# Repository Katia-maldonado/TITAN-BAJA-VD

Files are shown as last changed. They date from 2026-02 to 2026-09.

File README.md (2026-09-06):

## Baja SAE – Titan Racing Baja (2025-2026)
Titan Racing Baja SAE is a mechanical engineering club for students to design, build and race a custom off-road vehicle for the annual collegiate competition. Designing and building a car requires us to apply engineering problems to the real world. We gain invaluable skills in design, manufacturing, and project management that prepare us for professional careers. At **CSUF**, our Baja SAE team consists of 14 members, and our goal is to compete in the BAJA SAE Competion that is in Washougal, Washington in May 2026. We are divided into four subteams:

- Chassis / Ergonomics 
- Drivetrain  
- Suspension  
- Vehicle Dynamics / Data Acquisition  

---

## Vehicle Dynamics & Data Acquisition
For the **Vehicle Dynamics / Data Acquisition (VD/DAQ)** subteam, this focuses heavily on the electrical, sensor data, and data analysis work on the car.

We currently run **8 sensors** on the Baja car, all connected to an Arduino based DAQ system to record performance data during testing and competition runs. The system logs:

- Vehicle speed  
- Distance traveled  
- Time  
- Engine RPM  
- Secondary (CVT) RPM  
- Gyroscope data (roll, pitch, yaw)  
- 3-axis acceleration  
- Brake pressure bias  

All sensor data is routed through a **Teensy**, allowing each run to be logged directly to an microSD card. The recorded data is then processed and analyzed in **MATLAB** to evaluate vehicle performance, CVT behavior, braking balance, and driver inputs.

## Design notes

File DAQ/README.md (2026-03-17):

## System Overview

The DAQ system is responsible for collecting sensor data during testing and competition runs, logging it to an SD card. The on vehicle DAQ system is built around an **Arduino** paired with an **SD card reader shield**. Sensor inputs are recorded during each run and saved to an SD card for later analysis. This data is used to evaluate vehicle performance, driver behavior, and drivetrain response under real off road conditions.

Power for the DAQ system is supplied by the vehicle’s **12V battery**. A **buck converter** is used to step the voltage down from **12V to 5V** for sensors and components that require regulated 5V power, ensuring stable operation and protecting sensitive electronics.

---

## Sensors & Components

### Core DAQ Hardware
- Arduino  
- SD card reader shield  
- Buck converter (12V → 5V)

### Sensors / Inputs
- Brake Pressure Sensor (BPS)  
- Hall effect sensor – Secondary RPM  
- Spark plug RPM pickup – Primary RPM  
- IMU (gyroscope + accelerometer)  
- IR sensor (temperature monitoring)  
- GPS module (position / speed tracking)  
- Real Time Clock (RTC)  
- Push button (test control / marker)  
- LED indicators (system status)

---

## Data Logging & Output

During a run, sensor signals are routed into the Arduino, time stamped using the RTC, and logged to the SD card. Data is then transferred for processing and analysis in **MATLAB**, where it can be used to evaluate:

- Vehicle speed and distance trends  
- Engine and CVT RPM behavior  
- Brake pressure bias and braking consistency  
- Vehicle dynamics (roll, pitch, yaw, and acceleration)  
- Thermal behavior from IR sensor readings  
- GPS-based track mapping and run comparison  

---

## Live Transmission

In addition to SD logging, the DAQ system supports **live transmission** to allow real time monitoring during testing without removing the SD card.

### On-Vehicle Hardware (Transmitter)
- **XBee Pro 900HP – DMST**
- XBee Xplorer shield
- Antenna

### Base Station Hardware (Receiver)
- **XBee Pro 900HP – DMUT**
- Antenna

Live telemetry is primarily used during testing sessions to monitor system health and vehicle behavior in real time.

---

## To Do List

### Code  
- [x] SD card reader shield (data logging)  
- [x] Real-Time Clock (RTC) integration  
- [x] Brake Pressure Sensor (BPS)  
- [x] Hall effect sensor – Secondary RPM  
- [x] Spark plug RPM pickup – Primary RPM  
- [x] IMU (gyroscope + accelerometer)  
- [x] IR sensor (temperature monitoring)  
- [x] GPS module  
- [x] Push button (test control / marker)  
- [x] LED indicators (system status)  

### Live Transmission (Telemetry)
- [ ] XBee Pro 900HP – DMST (on-vehicle transmitter)  
- [ ] XBee Xplorer shield  
- [ ] Antenna (vehicle side)  
- [ ] XBee Pro 900HP – DMUT (base station receiver)  
- [ ] Antenna (base station)

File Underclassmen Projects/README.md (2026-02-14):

## Coding

I have a few underclassmen projects for anyone interested in writing code for **CVT tuning** and the **main DAQ harness** that will be installed on the car. These projects are a great opportunity to gain hands on experience with Arduino based data acquisition and sensor integration.

For coding related work, please reference **version 8 (v8)** of the code located in the **DAQ** or **version 9 (v9)** in the **CVT** folders. This version should be used as the baseline for development.

If you’re interested, **reach out to Katia on Discord**, and she can answer any questions you may have and help you get started.

---

### CVT DYNO

- [x] Add code to output **live data** onto a screen  
- [x] Display outputs for:
  - [x] Hall effect sensor (Primary RPM)  
  - [x] Hall effect sensor (Secondary RPM)  
  - [x] Hall effect sensor (Disk Brake RPM)  

---

### DAQ (On Vehicle)

- [ ] Code the **IMU (MPU-6050)** to record and send its data to the Arduino  
- [ ] Log IMU data onto an SD card using the **SD Card Reader Shield** (so it can be exported to Excel / MATLAB later)  
- [ ] IMU signals to record:
  - [ ] Angular velocity (gyro): **X, Y, Z**
  - [ ] Linear acceleration (accelerometer): **X, Y, Z**

> Note: The MPU-6050 is a 3-axis accelerometer and gyroscope. There are many examples available on GitHub and YouTube that can be used as references.

---

### Driver Dash Display

We are also exploring the addition of a **driver dash display** to provide live feedback during vehicle operation. The goal is to give the driver real time readings without relying on post run data analysis.

Planned display outputs include:
- Vehicle speed  
- Secondary RPM  
- CVT belt temperature (IR sensor)  

Due to the off road environment, the display must be **IP67-rated** to withstand dust, water, mud, and vibration. Many off the shelf IP67 displays are expensive, so part of this project is to find **cost effective display solutions** that can meet durability requirements.

This project may include:
- Researching low cost display options compatible with Arduino  
- Designing or selecting a **waterproof enclosure** for the screen  
- Integrating the display with the existing DAQ system  
- Ensuring readability in outdoor and high vibration conditions  

------

## CAD Fixes & Required Updates

The following items outline **specific fixes and updates** that need to be made to the existing CAD drawings for both the **CVT** and **DAQ** electrical harnesses. These updates are necessary to keep the CAD aligned with the actual electrical design and wiring standards.

---

#### CVT Harness CAD (DWG) Fixes

- Fix the electrical connections between the **battery, fuse, buck converter, and GND bus bar**
- Standardize **connector naming**:
  - All identical connectors (ex: all **JST-VH** connectors) should share the same label  
    - Example: all JST-VH connectors labeled as **C3**
- Add a **Quantity** column to the connector table
  - This applies to all repeating connectors
- Rename **BPS** to:
  - **Hall Effect – Brake Wheel RPM**

---

#### DAQ Harness CAD (DWG) Fixes

- Standardize **connector labeling**, following the same rules as the CVT harness
- Add a **Quantity** column to the connector table
- Fix electrical connections between the **battery, fuse, buck converter, and GND bus bar**
- Correct wiring errors where wires were accidentally placed in unused bus bar locations
- Add a **12V bus bar** and move the following components from 5V to **12V**:

**12V Components**
- Spark plug tachometer  
- BPS 1  
- BPS 2  
- Brake switch and brake light (wired in series)  
- Arduino  

**5V Components**
- Hall effect sensor  
- CVT infrared (IR) sensor  
- XBee Xplorer shield  
- IMU  
- GPS  

**GND Connections**
- GPS  
- Push button  
- LED  
- RTC  
- Arduino  
- Spark plug tachometer  
- BPS 1  
- BPS 2  
- Hall effect sensor  
- CVT IR sensor  
- XBee  
- Brake light  
- IMU  
- Buck converter (IN)  
- Buck converter (OUT)  

- **Sheet 3 Fix**:
  - Trim the **GND wire connected to the QWIIC adapter**
  - The wire is currently too long and should be shortened in the DWG

---

Maintaining accurate CAD drawings is critical for harness fabrication, troubleshooting, and future revisions. These fixes should be completed before final harness assembly.

## Sensors - Hands on testing

For those interested in hands on work, there are opportunities to help test and validate the sensors we are using by connecting them to an Arduino and breadboard while we wait for final parts to be delivered. This is a great way to get familiar with the hardware and basic wiring before full integration.

A future project will involve assisting with **harness assembly and integration** once all components arrive, including helping connect and route the wiring for the CVT dyno and on vehicle DAQ systems. Interested students should reach out to Katia for more information.

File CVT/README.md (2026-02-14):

## CVT Dyno Harness & Tuning Overview

In addition to the vehicle DAQ system, we are developing a **separate electrical harness for the CVT dyno**. This setup is designed specifically for **CVT testing and tuning** in a controlled environment and does not require the same level of durability as the on vehicle harness.

The CVT dyno harness uses an **Arduino Uno with an SD card reader shield** to log data and display real time feedback during testing. The system includes the following components:

- Hall effect sensor – Primary RPM  
- Hall effect sensor – Secondary RPM  
- Hall effect sensor – Disk Brake RPM  
- Push button (test control / reset)  
- LED indicators (system status)  
- Real Time Clock (RTC)  
- Display screen for real time output  

The hall effect sensors allow us to measure **primary, secondary, and wheel RPM**, which are critical for understanding CVT behavior under different load and throttle conditions. Data is logged to an SD card for analysis, while the display provides immediate feedback during testing.

---

## Purpose of CVT Tuning

The purpose of CVT tuning is to optimize the transmission’s performance by ensuring the engine operates within its ideal RPM range throughout acceleration and load changes. By analyzing the relationship between **primary RPM, secondary RPM, and wheel RPM**, we can evaluate:

- Shift behavior and ratio changes  
- Belt slip and engagement consistency  
- Backshift response under load  
- Overall drivetrain efficiency  

This data approach allows us to make informed adjustments to **spring rates, flyweights, and CVT setup** rather than relying solely on trial and error. The CVT dyno harness provides a repeatable testing environment that directly supports on vehicle performance improvements.

---

## To Do List

- [x] Hall effect sensor – Primary RPM  
- [x] Hall effect sensor – Secondary RPM  
- [x] Hall effect sensor – Disk Brake RPM  
- [x] Push button (test control / reset)  
- [x] LED indicators (system status)  
- [x] Real-Time Clock (RTC)  
- [x] Display screen for real-time output

---

## Final Code Notes
- V10: Leon, has outputs to both SD Card and external screen
- V10.5: Katia, has outputs to both SD card and Serial Monitor on laptop

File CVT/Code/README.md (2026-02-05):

## Code Notes & Versioning

**Note:** **Version 9 (v9)** is the most current and stable version of the CVT code. It has been tested using an **Arduino and breadboard** and should be used as the baseline for any new development.

All new code files must follow the updated naming convention:

Example:
- `v9_CVT_KM`

---

## Required Code Header Comment

Each CVT code file must include a **comment block at the very top** of the file describing what the code does and which sensors are used. This helps keep the repository organized and makes code review easier.

### Required Format (Copy & Paste)

```cpp
/*
Version: v#
Author: Name
System: CVT

Description:
- Brief description of what was added or changed

Sensors Included:
- List all sensors used in this code
*/

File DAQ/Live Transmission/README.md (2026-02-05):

# Live Transmission (Telemetry System)

This folder documents the **Live Transmission (Telemetry) system** used by the CSUF Titan Racing Baja SAE team. The purpose of this system is to wirelessly transmit selected vehicle data in real time during testing, allowing engineers to monitor system health and vehicle behavior without removing the SD card after each run.

This system is designed primarily for **testing and tuning**, especially in off-road and forested environments where visibility and access to the vehicle may be limited.

---

## System Overview

The live transmission system is built around **XBee Pro 900HP radios**, which operate in the 900 MHz band and are well-suited for long-range communication in obstructed terrain such as dirt tracks and wooded areas.

The system consists of:
- An **on-vehicle transmitter**, connected to the DAQ system
- A **base station receiver**, used by the team during testing

The live transmission system operates alongside SD card logging and does **not replace onboard data storage**. SD logging remains the primary data source, while telemetry provides immediate feedback.

---

## On-Vehicle Hardware (Transmitter)

The following components are mounted on the vehicle and integrated into the DAQ system:

- **XBee Pro 900HP – DMST**
- XBee Xplorer shield
- Antenna

The transmitter receives data from the Arduino DAQ system and sends selected data packets wirelessly to the base station in real time.

---

## Base Station Hardware (Receiver)

The base station setup is used by the team during testing sessions and includes:

- **XBee Pro 900HP – DMUT**
- Antenna

The base station receives telemetry data and allows engineers to observe vehicle behavior without stopping the run.

---

## Data Being Transmitted

Live transmission is intended to send **key parameters only**, rather than the full high-rate dataset stored on the SD card. Typical transmitted values include:

- Engine RPM  
- Secondary (CVT) RPM  
- Vehicle speed  
- Brake pressure  
- System status indicators  

Limiting the transmitted data helps maintain a stable wireless connection and reduces packet loss.

---

## Purpose of Live Telemetry

The primary goals of the live transmission system are to:

- Monitor vehicle performance in real time  
- Verify sensor operation during testing  
- Detect issues such as signal dropouts or abnormal readings  
- Reduce downtime between test runs  
- Support CVT tuning and drivetrain testing  

This capability allows the team to make quicker, data-informed decisions while testing, instead of relying solely on post-run analysis.

---

## Environmental Considerations

The telemetry system is designed with **off-road conditions** in mind, including:

- Operation in forested terrain  
- Long-range communication with obstructions  
- Resistance to vibration and electrical noise  

Antenna selection and placement play a critical role in system performance and are considered during testing.

---

## To Do List

### On-Vehicle (Transmitter Side)
- [ ] XBee Pro 900HP – DMST setup  
- [ ] XBee Xplorer shield integration  
- [ ] ANT-916-CW-RCS antenna  
- [ ] Power supply integration (from DAQ system)  
- [ ] Arduino → XBee serial communication    

### Base Station (Receiver Side)
- [ ] XBee Pro 900HP – DMUT setup
- [ ] UFL -> SMA Cable
- [ ] LMR 400 Coax Cable
- [ ] YA9-11 antenna 
- [ ] Base station power configuration  
- [ ] Data reception and parsing  
- [ ] Live data display / monitoring

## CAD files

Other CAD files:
CVT/CAD/v5/CVT_DYNO_V5_KM.dwg
Underclassmen Projects/Underclassmen Uploads/DAQ_TeensyROUGHWD_LN.dwg
CVT/CAD/v5/CVT_DYNO_BOM_WIRE_CONNECTORS_V5_KM.dwg

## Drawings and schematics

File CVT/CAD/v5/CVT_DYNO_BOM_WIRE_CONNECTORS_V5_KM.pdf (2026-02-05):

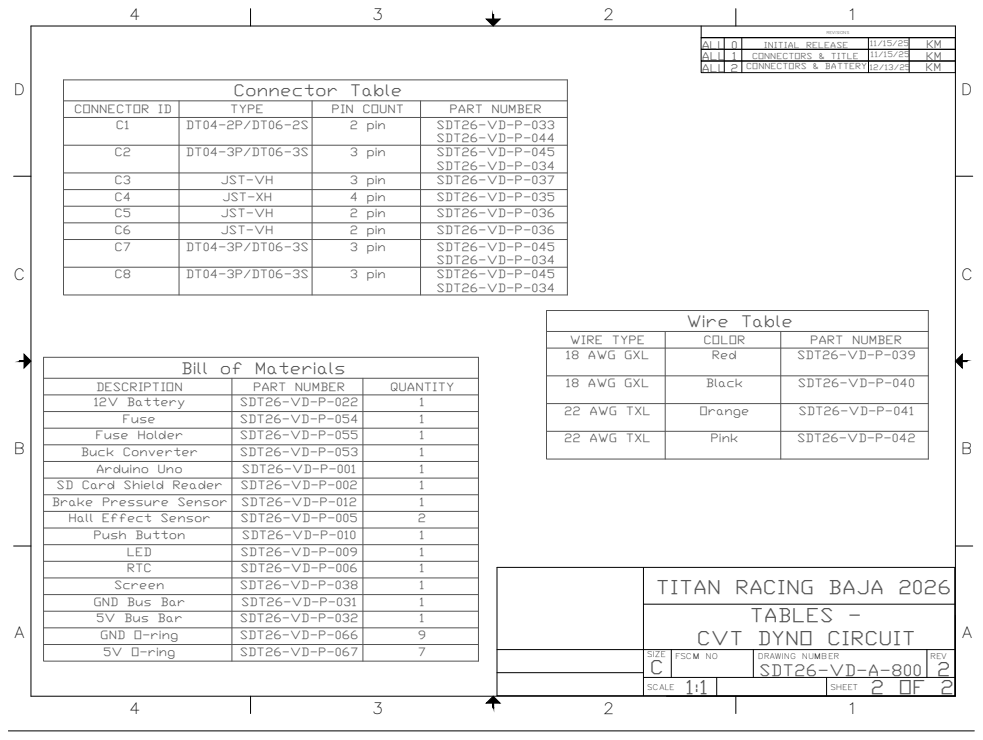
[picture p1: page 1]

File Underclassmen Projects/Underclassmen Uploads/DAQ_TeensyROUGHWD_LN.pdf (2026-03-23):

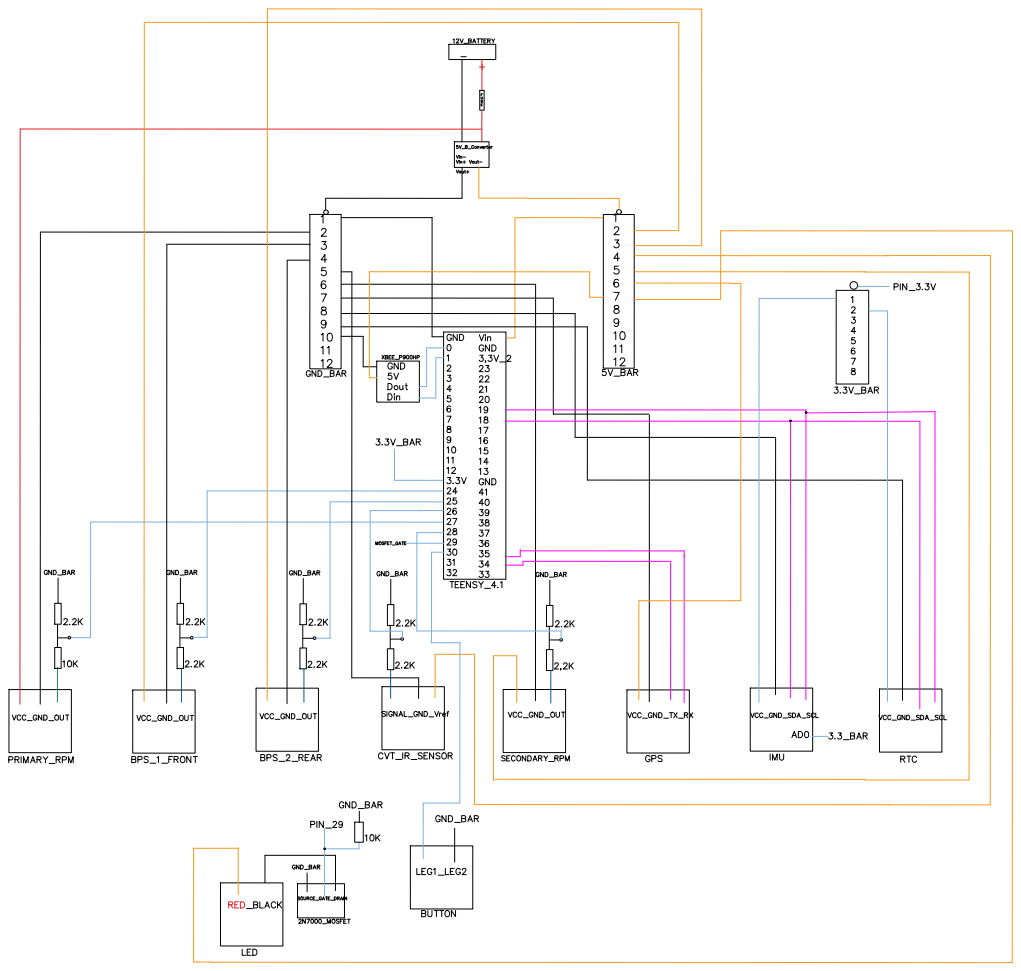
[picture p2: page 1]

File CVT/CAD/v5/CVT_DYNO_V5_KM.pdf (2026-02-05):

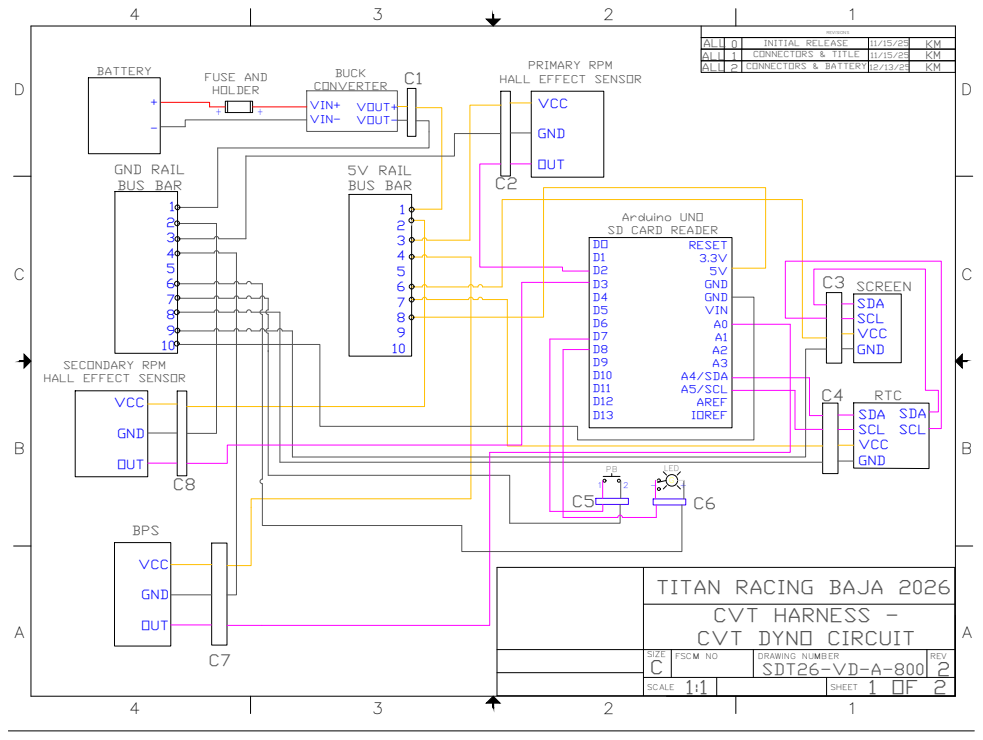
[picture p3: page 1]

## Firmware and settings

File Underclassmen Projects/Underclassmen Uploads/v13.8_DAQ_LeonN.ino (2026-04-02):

/*
Version: v13.8
Author: Leon Nguyen
System: DAQ

Description:
- Increased XBee baud rate to 115200 to prevent bottlenecks [REWORKED]
- Added dedicated XBee ring buffer logic for asynchronous transmission [NEW]
- Improved buffer overrun handling to safely drop old data instead of freezing [REWORKED]
- Optimized math operations (multiplication instead of division) for more efficient sensor readings [REWORKED]
- Optimized SD card flush interval to reduce loop stutters and preserve SD health [REWORKED]
- Added PMTK commands to configure GPS for 5Hz update rate for smoothness [NEW]
- Adjusted GPS Status Failsafe for improved visibility [REWORKED]
- Adjusted IMU axis for mounting in Teensy 4.1 enclosure [NEW]
- Utilizing Fast variants of digitalWrite and digitalRead for optimization. [REWORKED]
- Reworked BPS code as inital BPS was the incorrect model used [MAJOR]
- Removed VD for RPM_S and moved VCC to 3.3V [REWORKED]
- Exchanged CVT_IR VD for high-impedance VD [REWORKED]
- Adjusted GPS baud rate and optimized serial buffer [NEW]
- Added string copy safety to prevent printing of garbage data [NEW]

Sensors Included:
- Spark Plug RPM Adapter (Primary RPM)
- Hall Effect Sensor (Secondary RPM)
- DS3231 RTC (Real Time Clock)
- MPU-6050 (Accelerometer & Gyroscope)
- Adafruit Ultimate GPS Module (NMEA 115200 baud, 5Hz)
- Brake Pressure Sensor (Analog Front)
- Brake Pressure Sensor (Analog Rear)
- CVT Belt Temp Sensor (Analog AiM)

TEENSY 4.1 HARDWARE WIRING GUIDE

WARNING: Teensy 4.1 is STRICTLY 3.3V.
Do not plug 5V or 12V directly into pins, use Voltage Dividers!

--- COMMUNICATION PINS --- 
- IMU & RTC (SDA)        -> Pin 18 
- IMU & RTC (SCL)        -> Pin 19 
- GPS RX (Serial8 RX8)   -> Pin 34 (Connects to GPS module's TX pin)
- GPS TX (Serial8 TX8)   -> Pin 35 (Connects to GPS module's RX pin)
- XBee RX (Serial1 RX1)  -> Pin 0  (Connects to XBee's TX(DOUT) pin) 
- XBee TX (Serial1 TX1)  -> Pin 1  (Connects to XBee's RX(DIN) pin) 

--- ANALOG PINS --- 
- Front Brake Pressure   -> Pin 24 (Requires Shunt Resistor)
- Rear Brake Pressure    -> Pin 26 (Requires Shunt Resistor)
- CVT Belt Temp (AiM IR) -> Pin 38 (Requires 5V to 3.3V High-Impedance Divider)

--- DIGITAL PINS --- 
- Primary RPM (Spark)    -> Pin 10 (Requires 12V to 3.3V Divider)
- Secondary RPM (Hall)   -> Pin 12 (INTERNAL_PULLUP)
- LED Indicator          -> Pin 29 (Requires MOSFET + 1x 10k resistor)
- Push Button            -> Pin 30 (INTERNAL_PULLUP)

--- IMU SPECIFIC WIRING ---
- MPU6050 AD0 Pin        -> Wire to 3.3V power (Sets address to 0x69 for code)
*/

#include <Wire.h>
#include <SPI.h>
#include <SD.h>
#include <RTClib.h>
#include <Adafruit_MPU6050.h>
#include <Adafruit_Sensor.h>
#include <TinyGPS++.h>
#include <Watchdog_t4.h>

RTC_DS3231 rtc;
Adafruit_MPU6050 mpu;
TinyGPSPlus gps;
WDT_T4<WDT1> wdt;

// -------- Pins -------- 
const int pinRPM_Primary   = 10;   // AiM Adapter [12V DIVIDER]
const int pinRPM_Secondary = 12;   // Hall Sensor 
const int ledPin           = 29;
const int buttonPin        = 30;

// Analog Pins 
const int pinBrakeF        = 24;   // Front Brake (DataQ)   [SHUNT RESISTOR]
const int pinBrakeR        = 26;   // Rear Brake (DataQ)    [SHUNT RESISTOR]
const int pinCVT           = 38;   // CVT Temp (AiM Analog) [5V HIGH-IMPEDANCE DIVIDER]

// -------- Settings --------
const unsigned long SAMPLE_MS     = 50;   // 20Hz Sampling
const uint8_t       PPR           = 1;    // Pulses Per Rev
const unsigned long DEBOUNCE_MS   = 50;   // Button Debounce
const unsigned long RPM_DEBOUNCE  = 2000; // 2ms Lockout for Spark Noise

// --- Ring Buffer Settings --- 
const int BUFFER_SIZE = 100;       // Hold up to 100 lines of telemetry
char logBuffer[BUFFER_SIZE][256];
volatile int head = 0;             // Where new data is written to
volatile int tail = 0;             // Where data is read and saved to SD
volatile int xbeeTail = 0;         // Where data is read and sent to XBee [NEW]

// Voltage Divider Math (2.2k resistors)
// Ratio = 2200 / (2200 + 2200) = 0.5. To reverse it, we multiply by 2.0.
// WARNING!!! For 12V Primary Pin, use 10k TOP and 2.2k BOTTOM resistors
const float DIVIDER_MULTIPLIER = 2.0; // Math optimization (1 / 0.5 = 2.0) [REWORKED]
const float MINUTE_MICROS_PPR = 60000000.0 / PPR;

// -------- Counters / State --------
// Pulse counters for period tracking
volatile unsigned long lastTimeP = 0;
volatile unsigned long periodP = 0;

volatile unsigned long lastTimeS = 0;
volatile unsigned long periodS = 0;

bool logging      = false;
bool lastStable   = HIGH;
bool debouncing   = false;
unsigned long tDebounce = 0;

bool sdOk = false, rtcOk = false, mpuOk = false;
unsigned long t0_ms = 0; 
char filename[32]; 

File logFile;

// --- ISRs ---
// Primary RPM (AiM Adapter) - Rising Edge with Debounce
void isrP() { 
  unsigned long now = micros();
  // Using 2000us (2ms) lockout for Spark Noise
  if (now - lastTimeP > RPM_DEBOUNCE) { 
    periodP = now - lastTimeP;
    lastTimeP = now;
  }
}

// Secondary RPM (Hall) - Falling Edge
void isrS() { 
  unsigned long now = micros();
  // Using a 1000us (1ms) debounce for the Hall sensor to prevent noise double-triggers
  if (now - lastTimeS > 1000) { 
    periodS = now - lastTimeS;
    lastTimeS = now;
  }
}

// --- GPS Parsing --- 
void updateGPS() {
  while (Serial8.available() > 0) { 
    gps.encode(Serial8.read());
  }
}

// --- Build File Name ---
void buildNewRunFilename() {
  int run = 1;
  do {
    sprintf(filename, "RUN%03d.CSV", run); 
    run++;
  } while (SD.exists(filename));
}

// --- Write Header ---
void writeHeader() {
  // Added Speed, Brakes, and CVT columns to header
  logFile.println(F("Date,Time,P_RPM,S_RPM,AccX,AccY,AccZ,GyroX,GyroY,GyroZ,Lat,Lon,Speed_MPH,BrakeF_PSI,BrakeR_PSI,CVT_TempC"));
  logFile.flush();
  Serial.println(F("Header written"));
}

// --- Helper Functions --
// BPS model outputs 4-20mA [MAJOR]
float readPressurePSI(int pin) {
  int val = analogRead(pin);
  // Convert 10-bit ADC value to voltage based on 3.3V logic
  float pinVoltage = (val / 1023.0) * 3.3; 
  
  // If voltage is below 0.55V (just below the 4mA/0.6V baseline), 
  // the sensor is likely reading 0 PSI or is disconnected.
  if (pinVoltage < 0.55) {
    return 0.0; 
  }

  // Map the 0.6V - 3.0V range directly to 0 - 2000 PSI
  // (3.0V max - 0.6V min = 2.4V span)
  float psi = ((pinVoltage - 0.6) / 2.4) * 2000.0; 
  
  // Final safety check to prevent any negative readings due to minor voltage fluctuations
  if (psi < 0.0) return 0.0; 
  return psi;
}

float readTempC(int pin) {
  int raw = analogRead(pin);
  float pinV = raw * (3.3 / 1023.0);
  float sensorV = pinV * DIVIDER_MULTIPLIER; // Reverse voltage divider (Optimized to multiply) [REWORKED]
  
  // AiM Spec: 820mV = -20C, 2880mV = +250C
  if (sensorV < 0.8) return -20.0;
  float tempC = (sensorV - 0.82) * 131.07 - 20.0;
  return tempC;
}

void setup() {
  Serial.begin(9600);
  Wire.begin();
  Wire.setClock(400000);
  
  // I2C Timeout Failsafe 
  // No response in 10,000 microseconds (10ms) will timeout bus instead of freezing the Teensy
  Wire.setTimeout(10000);
  
    // --- Serial RX Buffer Memory Allocation --- [NEW]
  static char gpsBuffer[256];
  Serial8.addMemoryForRead(gpsBuffer, sizeof(gpsBuffer));

  Serial1.begin(115200); // Swapped for XBee (RX1 = 0, TX1 = 1) [REWORKED]

  Serial8.begin(9600);   // GPS module (RX8 = 34, TX8 = 35)
  Serial8.println(F("$PMTK251,115200*1F")); // Command to set GPS to 115200 [NEW]
  delay(100);
  Serial8.begin(115200); // Reconnect Teensy at the new high speed

  // Configure Adafruit Ultimate GPS to 5Hz and limit sentences to RMC & GGA [NEW]
  Serial8.println(F("$PMTK314,0,1,0,1,0,0,0,0,0,0,0,0,0,0,0,0,0,0,0*28"));
  delay(100);
  Serial8.println(F("$PMTK220,200*2C"));

  pinMode(ledPin, OUTPUT);
  digitalWriteFast(ledPin, LOW);
  pinMode(buttonPin, INPUT_PULLUP);
  
  // RPM Inputs [REWORKED]
  pinMode(pinRPM_Primary, INPUT);
  pinMode(pinRPM_Secondary, INPUT_PULLUP);
  
  // Analog Inputs
  pinMode(pinBrakeF, INPUT);
  pinMode(pinBrakeR, INPUT);
  pinMode(pinCVT, INPUT);
  analogReadResolution(10); 
  analogReadAveraging(16); // Hardware averages 16 samples for clean analog data

  attachInterrupt(digitalPinToInterrupt(pinRPM_Primary), isrP, RISING);
  attachInterrupt(digitalPinToInterrupt(pinRPM_Secondary), isrS, FALLING);

  Serial.println(F("Initializing Teensy 4.1 DAQ..."));
  
  sdOk = SD.begin(BUILTIN_SDCARD);
  Serial.print(F("SD: "));
  Serial.println(sdOk ? F("OK") : F("FAIL"));

  rtcOk = rtc.begin();
  if (rtcOk && rtc.lostPower()) {
    rtc.adjust(DateTime(F(__DATE__), F(__TIME__)));
  }
  Serial.print(F("RTC: ")); Serial.println(rtcOk ? F("OK") : F("FAIL"));
  
  if (!mpu.begin(0x69)) { 
    Serial.println(F("MPU6050 FAIL! Check the AD0 pin."));
    mpuOk = false;
  } else {
    Serial.println(F("MPU6050 OK"));
    mpuOk = true;
    mpu.setAccelerometerRange(MPU6050_RANGE_8_G);
    mpu.setGyroRange(MPU6050_RANGE_500_DEG);      
    mpu.setFilterBandwidth(MPU6050_BAND_21_HZ);
  }

  t0_ms = millis();
  Serial.println(F("Ready. Press Button."));

  // Initialize Watchdog Timer 
  WDT_timings_t config;
  config.trigger = 2;   // 2 second timeout
  config.timeout = 3;   // 3 second hard reboot
  wdt.begin(config);
  Serial.println(F("Watchdog Armed."));
}

void loop() {
  wdt.feed(); // Reset the watchdog countdown 
  unsigned long nowMs = millis();
  updateGPS();
  
  // --- Button Logic ---
  bool raw = digitalReadFast(buttonPin);
  
  if (!debouncing && raw != lastStable) { 
    debouncing = true; 
    tDebounce = nowMs;
  }
  
  if (debouncing && (nowMs - tDebounce) > DEBOUNCE_MS) {
    bool raw2 = digitalReadFast(buttonPin);
    if (raw2 != lastStable) {
      if (lastStable == LOW && raw2 == HIGH) { 
        if (!logging) {
          sdOk = SD.begin(BUILTIN_SDCARD);
          if (sdOk) {
            buildNewRunFilename();
            logFile = SD.open(filename, FILE_WRITE);
            if (logFile) {
              writeHeader();
              logging = true;
              digitalWriteFast(ledPin, HIGH);
              Serial.print(F("LOG ON -> ")); Serial.println(filename);
            }
          } else {
             for(int i=0; i<5; i++) { 
               digitalWriteFast(ledPin, HIGH);
               delay(50); 
               digitalWriteFast(ledPin, LOW); delay(50); 
             }
          }
        } else {
          logging = false;
          digitalWriteFast(ledPin, LOW);
          if (logFile) logFile.close(); 
          Serial.println(F("LOG OFF"));
        }
      }
      lastStable = raw2;
    }
    debouncing = false;
  }

 // --- Sampling Loop ---
  static unsigned long lastSample = 0;
  if (logging && (nowMs - lastSample >= SAMPLE_MS)) {
    lastSample = nowMs;
    
    // 1. Safely grab the latest periods and timestamps from interrupts
    noInterrupts();
    unsigned long pP = periodP;
    unsigned long tP = lastTimeP;
    unsigned long pS = periodS;
    unsigned long tS = lastTimeS;
    interrupts();
    
    // 2. Read Analog & IMU Sensors
    sensors_event_t a, g, temp;
    if (mpuOk) {
      if (!mpu.getEvent(&a, &g, &temp)) {
          // Bus timeout protected by Wire.setTimeout
      }
    }

    // --- AXIS REMAPPING --- [NEW]
    // Mapping Sensor to Car: Car X=Forward, Car Y=Lateral, Car Z=Vertical
    
    float carAccX = -a.acceleration.z; // Negative Z because +Z is rearward
    float carAccY =  a.acceleration.y; // Lateral
    float carAccZ =  a.acceleration.x; // Vertical (Gravity ~9.8 here)

    float carGyroX = -g.gyro.z;
    float carGyroY =  g.gyro.y;
    float carGyroZ =  g.gyro.x;

    float psiF = readPressurePSI(pinBrakeF);
    float psiR = readPressurePSI(pinBrakeR);
    float cvtTemp = readTempC(pinCVT);

    // 3. Calculate high-resolution RPM
    float rpmP = 0.0;
    float rpmS = 0.0;
    unsigned long nowMicro = micros();
    
    // Convert microseconds to minutes: 60,000,000us in a minute
    // Add a timeout: If half a second (500,000us) passes without a pulse, assume engine stopped
    if (pP > 0 && (nowMicro - tP < 500000)) {
        rpmP = MINUTE_MICROS_PPR / (float)pP;
    }
    if (pS > 0 && (nowMicro - tS < 500000)) {
        rpmS = MINUTE_MICROS_PPR / (float)pS;
    }

    // 4. Format the Data
    // Static buffer allocation for reducing memory fragmentation and overhead
    if (logFile) {
      static char dataLine[256];
      static char timeStr[32];
      static char imuStr[64];
      static char extraStr[64]; // Buffer for Brakes/Temp

      if (rtcOk) {
        DateTime dt = rtc.now();
        snprintf(timeStr, sizeof(timeStr), "%04d/%02d/%02d,%02d:%02d:%02d", 
                 dt.year(), dt.month(), dt.day(), dt.hour(), dt.minute(), dt.second());
      } else {
        snprintf(timeStr, sizeof(timeStr), "NoDate,%.3f", (nowMs - t0_ms) / 1000.0);
      }

      if (mpuOk) {
        // Use the CAR variables here for proper CSV display [NEW]
        snprintf(imuStr, sizeof(imuStr), "%.2f,%.2f,%.2f,%.2f,%.2f,%.2f", 
                 carAccX, carAccY, carAccZ, carGyroX, carGyroY, carGyroZ);
      } else {
        snprintf(imuStr, sizeof(imuStr), "0,0,0,0,0,0");
      }

      // Format Analog Sensors
      snprintf(extraStr, sizeof(extraStr), "%.0f,%.0f,%.1f", psiF, psiR, cvtTemp);
      
      // Compile the entire line including GPS Speed
      if (gps.location.isValid()) {
         snprintf(dataLine, sizeof(dataLine), "%s,%.0f,%.0f,%s,%.6f,%.6f,%.2f,%s", 
                  timeStr, rpmP, rpmS, imuStr, gps.location.lat(), gps.location.lng(), gps.speed.mph(), extraStr);
      } else {
         snprintf(dataLine, sizeof(dataLine), "%s,%.0f,%.0f,%s,0.000000,0.000000,0.00,%s", 
                  timeStr, rpmP, rpmS, imuStr, extraStr);
      }
      
      // Copy the formatted line into RAM buffer 
      int nextHead = (head + 1) % BUFFER_SIZE;
      if (nextHead != tail && nextHead != xbeeTail) { 
          strncpy(logBuffer[head], dataLine, 255);
          logBuffer[head][255] = '\0'; // String copy safety [NEW]
          head = nextHead;
      } else {
          Serial.println(F("Buffer OVERRUN! SD card is too SLOW. Dropping oldest data."));
          // Advance tails to forcefully drop the oldest frame and make room [REWORKED]
          if (nextHead == tail) tail = (tail + 1) % BUFFER_SIZE;
          if (nextHead == xbeeTail) xbeeTail = (xbeeTail + 1) % BUFFER_SIZE;

          strncpy(logBuffer[head], dataLine, 255);
          logBuffer[head][255] = '\0'; // String copy safety
          head = nextHead;
      }

      Serial.println(dataLine);
      // Serial1.println() was removed from here to prevent lagging the 50ms loop [REWORKED]

    } else {
      Serial.println(F("File Write FAIL!"));
      logging = false; 
      digitalWriteFast(ledPin, LOW);
    }
  }
  
  // --- GPS Status Failsafe --- [REWORKED]
  if (!logging) {
      // 1000ms cycle = Locked. 200ms cycle = Searching.
      unsigned long blinkInterval = gps.location.isValid() ? 1000 : 200; 
      
      // Modulo math creates a repeating cycle from 0 to the blinkInterval
      unsigned long currentPhase = millis() % blinkInterval;

      // Turn the LED ON for a sharp 50ms flash at the start of every cycle, then turn it completely OFF
      if (currentPhase < 50) {
          digitalWriteFast(ledPin, HIGH);
      } else {
          digitalWriteFast(ledPin, LOW);
      }
  }
  
 // --- Asynchronous SD Write --- 
  static unsigned long lastForceFlush = 0;
  if (logging && logFile) {
      // 1. Write one line to the SD card if the buffer has data
      if (head != tail) {
          logFile.println(logBuffer[tail]);
          tail = (tail + 1) % BUFFER_SIZE;
      }
          
      // 2. Force FAT table update ONLY every 2000ms to protect SD health [REWORKED]
      if (millis() - lastForceFlush > 2000) { 
          logFile.flush();
          lastForceFlush = millis();
      }
  }

  // --- Asynchronous XBee Transmission --- [NEW]
  // Sends data to the XBee whenever the Teensy has "free time", keeping the main loop fast
  if (logging && (head != xbeeTail)) {
      Serial1.println(logBuffer[xbeeTail]);
      xbeeTail = (xbeeTail + 1) % BUFFER_SIZE;
  }
}

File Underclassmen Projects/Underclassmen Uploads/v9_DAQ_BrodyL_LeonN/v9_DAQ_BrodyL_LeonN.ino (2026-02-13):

/*
Author: Brody Lister / Leon Nguyen
Version: v9
System: DAQ

Description:
- Implemented MPU-6050 IMU.
- Updated SD Log to include Accel and Gyro columns (x,y,z).
- RTC fixes (including updating time if power was lost).
- Optimized memory (F-Strings) to support additional libraries.
- Updated button logic to enable hot-swapping.
- Removed signs of Leon's vibe coding. -_- - Leon

Sensors Included:
- Hall Effect (Primary & Secondary RPM) [Foundation]
- DS3231 RTC (Real Time Clock) [Foundation]
- MPU-6050 (Accelerometer & Gyroscope) [NEW]
*/

#include <Wire.h>
#include <SPI.h>
#include <SD.h>
#include <RTClib.h>
#include <Adafruit_MPU6050.h>
#include <Adafruit_Sensor.h>

RTC_DS3231 rtc;
Adafruit_MPU6050 mpu;


// -------- Pins --------
const int SD_CS        = 10;
const int hallPrimary  = 2;
const int hallSecondary = 3;
const int ledPin       = 8;
const int buttonPin    = 7;

// -------- Settings --------
const unsigned long SAMPLE_MS   = 50;  // 20Hz Sampling
const uint8_t       PPR         = 1;   // Pulses Per Rev
const unsigned long DEBOUNCE_MS = 50;  

// -------- Counters / State --------
volatile unsigned long cntP = 0, cntS = 0;

bool logging     = false;
bool lastStable  = HIGH; 
bool debouncing  = false;
unsigned long tDebounce = 0;

bool sdOk  = false;
bool rtcOk = false;
bool mpuOk = false;

unsigned long t0_ms = 0; 
char filename[16]; 

// --- ISRs ---
void isrP() { cntP++; }
void isrS() { cntS++; }

// --- Build File Name ---
void buildNewRunFilename() {
  int run = 1;
  do {
    // 8.3 format: RUN001.CSV
    sprintf(filename, "RUN%03d.CSV", run); 
    run++;
  } while (SD.exists(filename));
}

// --- Write Header ---
void writeHeader() {
  File localFile = SD.open(filename, FILE_WRITE);
  if (localFile) {

    if (rtcOk) {
      localFile.println(F("Date,Time,P_RPM,S_RPM,AccX,AccY,AccZ,GyroX,GyroY,GyroZ"));
    } else {
      localFile.println(F("Time_s,P_RPM,S_RPM,AccX,AccY,AccZ,GyroX,GyroY,GyroZ"));
    }
    
    localFile.close();
    Serial.println(F("Header written"));
  } else {
    Serial.println(F("Header write fail"));
  }
}

void setup() {
  Serial.begin(9600);
  Wire.begin();

  pinMode(ledPin, OUTPUT);
  digitalWrite(ledPin, LOW);
  pinMode(buttonPin, INPUT_PULLUP);
  pinMode(hallPrimary, INPUT_PULLUP);
  pinMode(hallSecondary, INPUT_PULLUP);

  attachInterrupt(digitalPinToInterrupt(hallPrimary), isrP, FALLING);
  attachInterrupt(digitalPinToInterrupt(hallSecondary), isrS, FALLING);

  Serial.println(F("Initializing DAQ v9..."));

  // --- SD ---
  sdOk = SD.begin(SD_CS);
  Serial.print(F("SD: ")); Serial.println(sdOk ? F("OK") : F("FAIL"));

  // --- RTC ---
  rtcOk = rtc.begin();
  Serial.print(F("RTC: ")); Serial.println(rtcOk ? F("OK") : F("FAIL"));

  // rtcOk reads false at compile-time. Just check if rtc.lostPower() to adjust clock. [NEW]
  if (rtc.lostPower()) {
    rtc.adjust(DateTime(F(__DATE__), F(__TIME__)));
  }

  // Try to find MPU at address 0x69 first (AD0 = HIGH) to avoid RTC conflict
  if (!mpu.begin(0x69)) {
    Serial.println(F("MPU6050 not found at 0x69! Check AD0 pin (Connect to 3.3V)."));
    mpuOk = false;
  } else {
    Serial.println(F("MPU6050 OK"));
    mpuOk = true;
    
    // Configure settings for Baja vehicle dynamics
    mpu.setAccelerometerRange(MPU6050_RANGE_8_G); // 8G range (Bumps are >2G)
    mpu.setGyroRange(MPU6050_RANGE_500_DEG);      // Standard rotation speed
    mpu.setFilterBandwidth(MPU6050_BAND_21_HZ);   // Low pass filter (removes engine vibration)
  }

  t0_ms = millis();
  Serial.println(F("Ready. Press Button."));
}

void loop() {
  unsigned long nowMs = millis();

// --- Button Logic (Toggle) --- [NEW]
  bool raw = digitalRead(buttonPin);
  if (!debouncing && raw != lastStable) {
    debouncing = true;
    tDebounce = nowMs;
  }
  if (debouncing && (nowMs - tDebounce) > DEBOUNCE_MS) {
    bool raw2 = digitalRead(buttonPin);
    if (raw2 != lastStable) {
      
      // BUTTON RELEASED -> TOGGLE LOGGING
      if (lastStable == LOW && raw2 == HIGH) { 
        if (!logging) {
          // --- START LOGGING ---
          
          // Force SD card restart every time, which should allow ability to swap cards without resetting the Arduino.
          sdOk = SD.begin(SD_CS); 
          
          if (sdOk) {
            buildNewRunFilename(); // Scans card and finds next available number
            writeHeader();
            logging = true;
            digitalWrite(ledPin, HIGH);
            Serial.print(F("LOG ON -> ")); Serial.println(filename);
          } else {
            // If card is missing or broken
            Serial.println(F("SD Error - Insert Card"));
            // Blink LED as an indicator
            for(int i=0; i<5; i++) { 
              digitalWrite(ledPin, HIGH); delay(50); 
              digitalWrite(ledPin, LOW); delay(50); 
            }
          }
        } else {
          // --- STOP LOGGING ---
          logging = false;
          digitalWrite(ledPin, LOW);
          Serial.println(F("LOG OFF"));
        }
      }
      lastStable = raw2;
    }
    debouncing = false;
  }

  // --- Sampling Loop ---
  static unsigned long lastSample = 0;
  if (logging && (nowMs - lastSample >= SAMPLE_MS)) {
    lastSample = nowMs;

    // 1. Grab RPM Counts (Foundation)
    noInterrupts();
    unsigned long nP = cntP;
    unsigned long nS = cntS;
    cntP = 0; cntS = 0;
    interrupts();

    // READ SENSOR EVENTS
    sensors_event_t a, g, temp;
    if (mpuOk) {
      mpu.getEvent(&a, &g, &temp);
    }

    // 3. Calculation (Foundation)
    float rpmP = (nP * (60000.0 / SAMPLE_MS)) / PPR;
    float rpmS = (nS * (60000.0 / SAMPLE_MS)) / PPR;

    // 4. Write to SD
    File localFile = SD.open(filename, FILE_WRITE);
    if (localFile) {
      // Time (Foundation)
      if (rtcOk) {
        DateTime dt = rtc.now();
        localFile.print(dt.year()); localFile.print('/');
        localFile.print(dt.month()); localFile.print('/');
        localFile.print(dt.day()); localFile.print(',');
        localFile.print(dt.hour()); localFile.print(':');
        localFile.print(dt.minute()); localFile.print(':');
        localFile.print(dt.second()); localFile.print(',');
      } else {
        localFile.print((millis() - t0_ms) / 1000.0, 3);
        localFile.print(',');
      }

      // RPM (Foundation)
      localFile.print(rpmP, 0); localFile.print(',');
      localFile.print(rpmS, 0); localFile.print(',');
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

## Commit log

2026-02-04 Add MATLAB to the list of sensors
2026-03-17 Mark sensors as completed in README
    Updated the status of several sensors to completed in the README.
2026-03-17 Update hardware description from Arduino to Teensy
